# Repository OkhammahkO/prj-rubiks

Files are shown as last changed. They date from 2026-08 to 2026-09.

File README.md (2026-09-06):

# Rubee - Scans and solves a rubiks cube.
A Home Assistant + ESPHome remake of [CUBOTino](https://www.instructables.com/CUBOTino-Autonomous-Small-3D-Printed-Rubiks-Cube-R/)

💬 [Discuss on the Home Assistant Community forum](https://community.home-assistant.io/t/rubee-scans-and-solves-a-rubiks-cube/1024172?u=mahko_mahko)

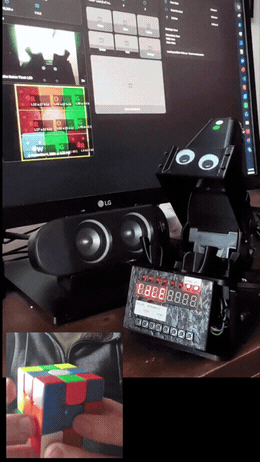
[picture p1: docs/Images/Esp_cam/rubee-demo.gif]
Rubee, the robot, demo


Main differences in this build:
- A HACS component and ESPHome talk to each other and split the work of cube scanning and solving.
- **ESP32-S3-CAM** instead of a Raspberry Pi Zero 2 W (or Zero W) + Pi Camera. Built in LED. ([board](https://github.com/nulllaborg/esp32s3-cam), [buy](https://www.aliexpress.com/item/1005012148685931.html))
- HACS component does colour detection and kociemba solving.
- ESPHome does camera control and implementing the solution.
- **Top-mounted camera with light-blocking hood** - consistent scans regardless of room lighting.
- **TM1638 display with 8 LEDs and buttons + buzzer built into the robot** — live status, audio feedback, and solve/stop/scramble/home controls.

User beware, most of the porting of this project and additional development and docs was vibe coded 💩.

---

## Dashboard

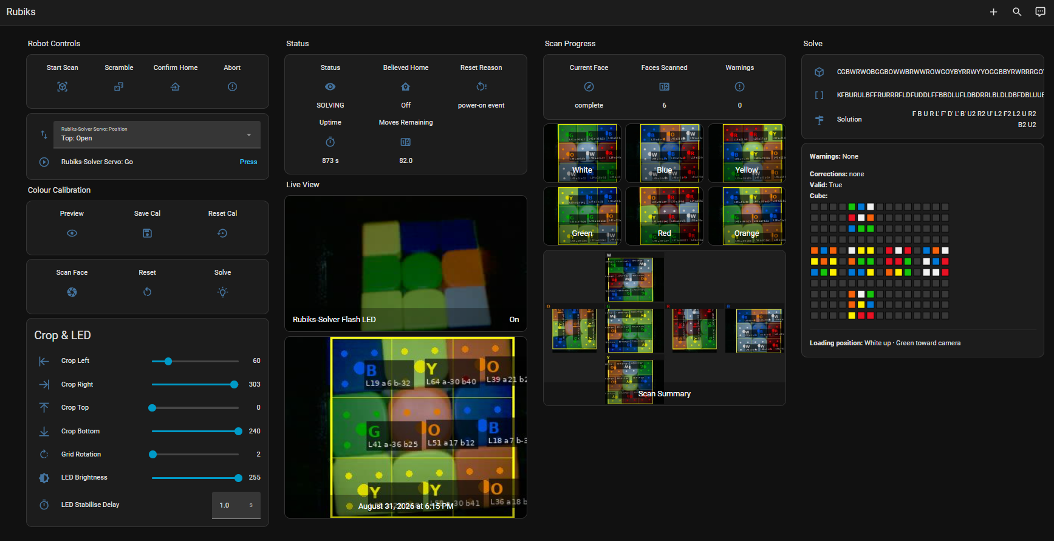
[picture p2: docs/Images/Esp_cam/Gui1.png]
Rubiks dashboard


---

## Setup

 - Don't expect magic out of the box - like the original, servo and colour calibration take some patience to dial in.
  - Assembly generally follows the original - I haven't documented my own variations here. I've been pretty sparse with details of my build and the set-up (except for AI generated docs, some of which might be stale). But happy to develop detail if there's interest.

1. Install the software - HACS component + flash `rubiks-solver.yaml`.
2. Build the hardware - 3D-printed frame and servos per Andrea's "Top" version
3. Calibrate - servo positions/timings, then colour detection.

---

## Docs

- [Architecture / integration spec](docs/spec.md)
- [Robot hardware + ESPHome component](docs/robot.md)
- [Servo tuning reference](docs/servo-tuning.md)
- [Camera/cube orientation model](docs/orientation.md)
- [Collision prevention](docs/collision-prevention.md)
- [TM1638 display/buzzer/buttons](docs/tm1638.md)
- [Feature/entity inventory](docs/features.md)

---

## Extras

- Need a cube? [MoYu RS3M V5 3x3](https://www.aliexpress.com/item/1005006116653775.html)  - cheap, decent, magnetic. Learning on a magnetic cube is way better and should make it easier for the robit too.
- Want to learn to solve one by hand? [This playlist](https://www.youtube.com/playlist?list=PLUprj8UXelXGXLTvO5RaJ92_yJxOwd957) is fun if you've got a little patience.

---

## License / Credits

[MIT](LICENSE) for this project's software, except `custom_components/rubiks` which is [GPLv3+](custom_components/rubiks/LICENSE) — it depends on `twophase` for cube solving, since `kociemba` doesn't install reliably on Home Assistant OS. The physical CUBOTino design/mechanism is Andrea Favero's - see [his Instructables page](https://www.instructables.com/CUBOTino-Autonomous-Small-3D-Printed-Rubiks-Cube-R/) for terms on the design itself. Googly eyes as per  [Andreas Spiess's build](https://youtu.be/G5Ii6ENUXEs).

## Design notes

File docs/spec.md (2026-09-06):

# Rubiks Cube Scanner — Technical Specification

## System Overview

```
ESP32-CAM (ESPHome) ──► HA Integration ──► Kociemba Solver ──► ESP32 Robot (ESPHome)
     camera entity       cube state string    move sequence        motor control
```

Camera scanning and cube-state detection can run standalone (Phase 1/2, manual/webcam
workflow) or driven by the robot (Phase 3, `docs/robot.md`). Both share the same
`SCAN_SEQUENCE` and colour-detection pipeline.

## File Structure

```
custom_components/rubiks/
├── __init__.py           — integration setup, hass.data initialisation, platform list
├── manifest.json         — domain, requirements (Pillow, kociemba)
├── const.py              — DOMAIN, CUBE_COLORS, SCAN_SEQUENCE, SCAN_MOTION,
│                           SCAN_LOADING_HINT, COLOUR_EMOJI, crop keys, device info
├── config_flow.py        — source selection (camera entity or sample image path)
├── cal_store.py          — CalibrationStore: persistent LAB anchor management
├── camera_processor.py   — CIELAB detection, calibration, image annotation,
│                           summary image generation, parity checks
├── solver.py             — kociemba sticker remapping, build_kociemba_faces(),
│                           kociemba_string(), solve()
├── button.py             — Scan Face, Preview Crop, Reset Scan, Save/Reset Calibration,
│                           Solve, Scramble, Robot Start Scan/Stop/Abort/Advance Face
├── image.py               — Last Scan, per-face images, Scan Summary
├── number.py              — Crop Left/Top/Right/Bottom, Crop Rotation, LED Brightness,
│                           LED Stabilise Delay, Scramble Move Count
├── text.py                — LED entity ID override
├── sensor.py               — Cube State, Current Face, Faces Scanned, Scan Warnings,
│                           Kociemba Input, Solution
├── services.yaml         — schema for the rubiks.robot_scan_face / rubiks.solve services
├── rubiks_dashboard.yaml — example Lovelace dashboard
├── strings.json / translations/en.json
└── tests/                  — CIELAB, detection, calibration, sticker remap, kociemba logic
```

## Architecture Decisions

**CIELAB, not HSV.** HSV hue is unreliable on this camera sensor; CIELAB with weighted
distance (`L×1.5, a×2.0, b×2.0`) separates cube colours more robustly. L is weighted
*above* a/b — unusual, but on this specific OV2640 unit Red and Orange are cleanly
separated by lightness more reliably than by chroma (see "Red/Orange Separation" below
for the actual L ranges). A different camera might not have this separation and would
need revisiting.

**Factory reference LAB values** are placeholders, not all camera-tuned. Only R and O
were actually measured on this specific unit (centre-square readings, two sessions,
very consistent); W/Y/B/G are borrowed from a different unit entirely and are expected
to be replaced by Save Calibration after a clean scan on your own camera:

| Colour | L | a | b |
|---|---|---|---|
| W | 66.0 | 16.0 | -15.0 |
| Y | 74.0 | -1.0 | 26.0 |
| R | 35.0 | 50.0 | 22.0 |
| O | 62.0 | 47.0 | 27.0 |
| B | 32.0 | 33.0 | -51.0 |
| G | 45.0 | -15.0 | 14.0 |

Unknown threshold: `_LAB_UNKNOWN_THRESHOLD = 80.0` (weighted units).

**5-point majority vote per cell** (centre + 4 inner corners at ¼ cell offset). Majority
vote tolerates 1-2 glare-affected points outvoting correctly; median LAB would instead
average a desaturated point into the result, risking misclassification.

**Per-session calibration with persistent EMA.** After all 6 faces scan,
`calibrate_faces()` runs a two-round greedy constrained assignment (max 9 per colour) to
refine anchors, blended into persistent storage via EMA (α=0.2) if parity is valid, or
hard-committed via Save Calibration. Centre stickers are locked (pre-assigned before the
greedy competition) since loading-position enforcement makes them ground truth — this
prevents a close competing colour from contaminating round-1 anchor recomputation.
Round-2 anchors use median LAB per cluster (not mean), so a single misassigned outlier
from round 1 doesn't drag the anchor toward it.

**Loading position enforcement.** Face labels are assigned by scan position
(`SCAN_SEQUENCE[len(scanned_faces)]`), not by classifying the centre square — this
eliminates Red/Orange centre-identification ambiguity entirely. A LAB sanity check still
warns if a detected centre is >20 units from its expected reference.

**Crop region and LED brightness as runtime number entities**, not config-flow fields —
tunable live via dashboard sliders with Preview Crop for immediate feedback.

**LED brightness and LAB values**: all absolute L values shift with LED brightness.
Changing brightness significantly requires Reset Calibration → rescan → Save
Calibration to re-establish anchors.

**Kociemba sticker remapping** (`solver.py`) maps each scan position's camera-grid index
to kociemba's canonical face-position index:

| Face | Remap | kociemba canon-top | kociemba canon-left |
|---|---|---|---|
| W (U) | Identity | B-side | L |
| B (B) | 180° | U (=W) | R |
| Y (D) | Identity | F-side | L |
| G (F) | Identity | U | L |
| O (L) | Identity | U | B |
| R (R) | Identity | U | F |

**Phase 3 (robot) key decisions** — full detail in `docs/robot.md` and
`docs/collision-prevention.md`:
- Kociemba runs in HA, not on the ESP32 (two-phase pruning tables need 10-20MB RAM).
- Servo step queue is non-blocking, pre-planned into `std::vector<ServoStep>`, drained
  one entry per `loop()` tick.
- Raw MicroPython PWM duty (0-1023, from `Cubotino_settings.txt`) converts to ESPHome's
  -1.0..1.0 via `duty_to_esphome()` in C++ only.

**Already-solved short-circuit**: `solve()` checks `_is_solved()` and returns `""`
directly before ever calling the underlying solver, rather than relying on it to
handle a trivial already-solved input correctly.

## Shared Data (`hass.data[DOMAIN][entry_id]`)

| Key | Type | Description |
|-----|---|---|
| `scanned_faces` | `dict[str, list[str]]` | face_label → 9 colour codes |
| `face_scans` | `dict[str, FaceScan]` | dataclass per face (colours + LAB readings) |
| `face_annotated_images` | `dict[str, bytes]` | per-face annotated JPEG |
| `calibration_result` | `CalibrationResult \| None` | most recent calibration |
| `summary_image` | `bytes \| None` | cross-net-layout JPEG (see `_SUMMARY_NET_POSITIONS`) |
| `last_annotated_image` | `bytes \| None` | most recent scan or preview |
| `image_size` | `tuple[int, int] \| None` | (width, height) of the last-loaded image, feeds crop slider max |
| `scan_warnings` | `list[str]` | current plain-English warnings |
| `crop_entities` | `dict[str, CropNumberEntity]` | registered crop number entities, keyed by entity key |
| `led_entity_id` | `str \| None` | configured LED light entity ID |
| `led_brightness_entity` | `LedBrightnessEntity \| None` | registered LED Brightness entity |
| `led_stabilise_delay_entity` | `LedStabiliseDelayEntity \| None` | registered LED Stabilise Delay entity |
| `scramble_move_count_entity` | `ScrambleMoveCountEntity \| None` | registered Scramble Move Count entity |
| `cal_store` | `CalibrationStore` | persistent LAB anchor store |
| `kociemba_faces` | `dict[str, list[str]] \| None` | built from `scanned_faces` after calibration |

The solve result isn't stored in `hass.data` — it only ever exists transiently in the
`rubiks_solved` event payload and in the Solution sensor's own entity state.

## Pipelines

**Colour detection**: image → optional crop → 3×3 grid → per-cell 5-point CIELAB
classification + majority vote → `override_centre` (loading-position label) →
`_annotate_image()` → `FaceScan`.

**Calibration** (after 6th face): build anchors from centres → greedy round 1 (centres
locked) → recompute anchors (median) → greedy round 2 → confidence margins → flag
low-confidence (<0.15 margin) → `check_cube_parity()` → `CalibrationResult` → EMA update
if valid → `build_kociemba_faces()` → fire `rubiks_calibrated`.

**Solver** (Solve button): `kociemba_string()` → `_is_solved()` short-circuit →
`twophase.solver.solve()` via executor job (see `docs/features.md` "Solver
dependency") → solution string or `""` ("Already solved!") → fire `rubiks_solved`.

## Scan Sequence (Phase 1/2 manual/webcam)

Loading position: **White facing camera, Blue at top, Orange on left.**

| Step | Face | Motion | Camera-top | Camera-left | kociemba face |
|---|---|---|---|---|---|
| 1 | White | Load | Blue | Orange | U |
| 2 | Blue | Tilt backward | Yellow | Orange | B |
| 3 | Yellow | Tilt backward | Green | Orange | D |
| 4 | Green | Tilt backward | White | Orange | F |
| 5 | Red | Rotate left | White | Blue | R |
| 6 | Orange | Rotate 180° | White | Green | L |

Matches `SCAN_SEQUENCE = ["W","B","Y","G","R","O"]` and `SCAN_MOTION` in `const.py` —
the same list the robot service schema validates against.

## Validation Checks

| Check | When | Action |
|---|---|---|
| LAB centre vs expected colour | Each scan | Warning if distance > 20 units |
| No colour > 9 across scanned faces | After each scan | Warning |
| Each colour appears as centre once | After face 6 | Warning if missing/unexpected |
| Centre sticker matches face label | After calibration | Warning (Red/Orange confusion indicator) |
| Exactly 54 stickers, 6×9 | After calibration | `parity_valid`/`parity_error` |
| Structural cube validity | After calibration | `diagnose_cube_string()` |
| Low-confidence stickers | After calibration | Flagged, not blocking |
| Valid cube state | On Solve | Solver returns an error string if impossible (not an exception) |

## Services

| Service | Description | Returns |
|---|---|---|
| `rubiks.robot_scan_face` | Illuminate → capture → detect → store for one face | — |
| `rubiks.solve` | Run kociemba solver against stored face scans | `{solution, move_count, cube_string}` on success; on failure `{error, solution: "", move_count: 0}` (no `cube_string`) |

## Events

| Event | Payload | Fired by |
|---|---|---|
| `rubiks_face_scanned` | `{face, colors, warnings}` | ScanFaceButton |
| `rubiks_scan_rejected` | `{}` | PreviewCropButton |
| `rubiks_scan_reset` | `{}` | ResetScanButton, RobotStartScanButton, RobotAbortButton |
| `rubiks_calibrated` | `{parity_valid, corrections, low_confidence, anchors_saved, kociemba_string}` | ScanFaceButton |
| `rubiks_solved` | `{solution, move_count, cube_string}` | SolveButton, `rubiks.solve` |
| `rubiks_calibration_saved` / `rubiks_calibration_reset` | — | Save/Reset Calibration buttons |
| `rubiks_robot_start_requested` / `_stop_requested` / `_advance_face_requested` | `{}` | Robot buttons |

## Cube State String Formats

**Human-readable** (Cube State sensor): 54 chars, scan order (`W B Y G R O`), letters
`W Y R O B G`.

**Kociemba Input sensor**: 54 chars, kociemba face order (`U R F D L B`), letters
`U R F D L B`. Produced by `solver.kociemba_string(kociemba_faces)`.

## Red/Orange Separation — Camera-Specific Notes

Hardest pair to separate (adjacent hue, differ mainly in lightness/saturation). On this
camera: Red L≈14-38, Orange L≈40-63 (`camera_processor.py`'s `_L_WEIGHT` comment — the
single source of truth for these ranges; older revisions of this doc quoted slightly
different numbers, now removed to avoid drifting out of sync again) — only a small gap
between the darkest Orange corner and brightest Red corner, so a/b still matters for
borderline cells even with L weighted higher.

Centroid-based anchors (post-calibration) classify borderline dark-Orange corners
correctly; centre-square-only anchors place the decision boundary too high and risk
misclassifying them as Red on the first scan, before calibration's two-round greedy
corrects it.

Glare on Red can desaturate b toward White's range; majority vote tolerates this unless
3+ of the 5 sample points are affected.

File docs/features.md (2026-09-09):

# Rubiks Cube Scanner — Feature Tracking

## Phase 1 — Cube State Detection ✅

Reliably scan all 6 faces and produce a valid 54-character cube state string.

**Detection**: CIELAB classification (`L×1.5, a/b×2.0` weighted distance), 5-point
majority vote per cell (centre + 4 inner corners, glare-tolerant), median LAB per cell
for display.

**Loading position enforcement**: fixed scan sequence `SCAN_SEQUENCE = ["W","B","Y","G","R","O"]`;
face label assigned by sequence position, not centre classification — eliminates
Red/Orange centre-identification ambiguity. LAB sanity check warns if a detected centre
deviates >20 units from its expected reference.

**Calibration**: per-session greedy constrained assignment (max 9/colour) with centroid
refinement; confidence margins flag low-confidence stickers (<0.15); EMA blend (α=0.2)
persisted after every parity-valid session; manual Save/Reset Calibration buttons;
survives restarts (`.storage/rubiks_cal_<entry_id>`).

**Validation**: running colour-count check, centre-uniqueness check (after face 6),
parity check (exactly 9 of each colour), `parity_valid`/`parity_error` sensor attributes.

**Entities**: Scan Face / Preview Crop / Reset Scan / Save Calibration / Reset
Calibration buttons; Last Scan, 6 per-face images, Scan Summary (cross-net layout via
`_SUMMARY_NET_POSITIONS`) images; Crop Left/Top/Right/Bottom, Crop Rotation, LED
Brightness, LED Stabilise Delay numbers; LED entity ID override text; Cube State,
Current Face, Faces Scanned, Scan Warnings sensors.

**Annotated overlay**: crop boundary, 3×3 grid, colour-coded sample dots, per-cell
colour label + LAB values, semi-transparent legibility backgrounds. Overlay points are
un-rotated back to the original image frame before drawing (`_unrotate_point()`) so they
align correctly even when `Crop Rotation` is non-zero.

**Config**: options flow allows changing source/camera entity without re-adding the
integration, plus an optional LED entity override selector. LED entity auto-discovery
resolves the camera's device, finds `light` domain entities on it, auto-selects if
exactly one.

**Testing**: run `pytest custom_components/rubiks/tests/ -v` for the current count
(colour detection, calibration, solver logic) — not duplicated here since it drifts
every time a test is added. 13 synthetic sample images in `tests/samples/`.

**Open**: cube net display verification.

---

## Phase 2 — Solver ✅

Take the cube state string and produce a move sequence.

`solver.py`: camera grid index → kociemba face-position index remap per scan position
(`CAMERA_TO_KOCIEMBA_REMAP` for Phase 1/2, `ROBOT_CAMERA_TO_KOCIEMBA_REMAP` for the robot
— see `docs/orientation.md`); populates `kociemba_faces` after calibration.
`solver.solve()` wraps `twophase.solver.solve()` via `async_add_executor_job` (not
the `kociemba` package — see "Solver dependency" below), with a `_is_solved()`
short-circuit before calling it either way. Kociemba Input and Solution sensors expose
the string and move sequence. Verified against a physical cube end-to-end.

**Solver dependency**: uses `twophase` (pure Python, GPLv3+ — see
`custom_components/rubiks/LICENSE`), not `kociemba`. `kociemba` ships no Linux wheels
and its C-extension build fails on Home Assistant OS's sandboxed, musl-based install
environment; `twophase` needs no compiled extension at all, at the cost of needing its
pruning tables pre-built rather than generated on first use (30+ minutes in pure
Python). Shipped compressed as `custom_components/rubiks/twophase_tables.tar.gz`
(~33MB vs ~70MB raw) and extracted to a sibling `twophase_tables/` directory
(gitignored — a local runtime artifact, not tracked) the first time `solve()` runs
after install/update — plain stdlib `tarfile` decompression, no compiler involved, so
none of the HAOS build issues that ruled out `kociemba` apply. `twophase.defs.FOLDER`
is redirected to that extracted path before first import — see `solver.solve()`'s and
`_ensure_tables_extracted()`'s docstrings.

**Open**: cube net display verification.

---

## Phase 3 — Robot

Physically solve the cube using an ESP32-S3 robot adapted from CUBOTino. Automates both
scanning and solution execution. Architecture: `docs/robot.md`. Cross-servo timing:
`docs/collision-prevention.md`.

**Kociemba runs in HA, not the ESP32** — the two-phase pruning tables need 10-20MB RAM;
the ESP32-S3 has 8MB PSRAM.

### ESP32-S3 component

External C++ component (`esphome/components/rubiks_solver/`): `moves.h` (port of
`Cubotino_moves.py` — orientation tracking, `MOVES_TABLE`, `robot_required_moves()`),
`rubiks_solver.cpp` (`plan_flip_/spin_/rotate_/ensure_cover_*`, `plan_solution_()`,
non-blocking `loop()`). Servo position/timing defaults from `Cubotino_settings.txt`,
converted to ESPHome -1.0..1.0 via `duty_to_esphome()`. All values YAML-configurable
live via HA number entities. `auto_detach_time: 5s` on both servos (must exceed the
longest step duration to avoid mid-travel dropout).

### Scan flow

`start_scan()`/`advance_scan()` plan each face's moves (`SCAN_FACES = {"W","B","Y","G","R","O"}`,
matching `SCAN_SEQUENCE`), fire `esphome.rubiks_face_ready` per face, and after all 6,
run a `flip → spin_home → flip` return-to-start sequence (no `rotate`, so no D-layer
side effect) before firing `esphome.rubiks_scan_complete`. The robot bridge
(`custom_components/rubiks/robot_bridge.py`) relays `rubiks_face_ready` →
`rubiks.robot_scan_face` → `face_scan_done`, and `rubiks_scan_complete` →
`rubiks.solve` → `execute_solution`.

### Solve flow

`execute_solution()` translates the kociemba string through `moves.h` into a full servo
step queue, drained non-blocking by `loop()`. Fires `esphome.rubiks_solve_done` on
completion and returns straight to `IDLE` (no separate lingering `DONE` state).

### ESP32 API actions / events

Actions (HA→ESP32): `start_scan`, `face_scan_done`, `execute_solution` (returns
`{accepted, move_count}` via `api.respond`), `stop`, `confirm_safe_and_home`.
Events (ESP32→HA): `rubiks_face_ready {face}`, `rubiks_scan_complete`,
`rubiks_solve_done`.

### Safety / state machine

Full mechanism detail lives in the dedicated docs, not here — this is just the
inventory of what exists:

- Unclean-reset boot gate + `needs_confirm_before_move_` (also set when `stop()`
  interrupts a non-`IDLE` state) — `docs/robot.md` "Safety and timing".
- Two-layer cross-servo timing guard (plan-time + dispatch-time) —
  `docs/collision-prevention.md`.
- `SERVO_TEST` state drains a planned step queue then returns to `IDLE`; used by every
  diagnostic test button and the boot glide.
- `believed_home_` / `binary_sensor.rubiks_solver_believed_home` — optimistic home
  tracking, hard-blocks `start_scan()`/`execute_solution()` like
  `needs_confirm_before_move_` — `docs/servo-tuning.md` "Believed-home safeguard".

### Diagnostic entities

`solver_status` text sensor drives the TM1638 display, RTTTL beeps, and LED routines —
full status→feedback mapping in `docs/tm1638.md`. Servo test buttons (raw position
writes + planned cycles: rotate/spin/flip/scan-cycle/return-home), plus one shared
"Test: Run" button that dispatches based on a select entity's 18 single
kociemba-notation move options (`U`/`U2`/`U3`.../`B3`) — calls `execute_solution()`
directly for isolated move testing. 16 of 17 conceived calibration number entities are
live (`Top: Release Offset` remains commented out — its parameter sits at 0, a no-op
matching `Cubotino_settings.txt`'s own default); current values in `docs/servo-tuning.md`.
`Speed Multiplier` scales all step durations at plan time (currently 1.0× — the jam
cause turned out to be a servo calibration issue, not timing, so the earlier
precautionary bump was reverted). `reset_reason` diagnostic sensor.

### Versioning

`INTEGRATION_VERSION` (`const.py`) reads `manifest.json` at import time — single source
of truth, shown as `sw_version` on every HA device page. `esphome.project.name`/`version`
does the same for the ESP32 device page.

### HA side

`rubiks.robot_scan_face` service (`{face}`) runs illuminate→capture→detect→store,
schema-validated against `SCAN_SEQUENCE`. `rubiks.solve` service
(`SupportsResponse.OPTIONAL`) shared with the Solve button via `async_handle_solve()`.
4 robot control buttons (Start Scan / Stop / Abort / Advance Face) fire HA events rather
than calling ESPHome services directly, so automations are the single coupling point.

**Open**: soft guard in `ScanFaceButton` to refuse a press while the robot is scanning —
low priority.

### Hardware

Pinout, power, and calibration history: `docs/robot.md` "Hardware",
`docs/servo-tuning.md`.

### TM1638 display + buzzer + LEDs

Display, buzzer, LED routines, physical-button actions, transient error/rejection
feedback, and brightness control all implemented — full detail and current
status→feedback mapping in `docs/tm1638.md`. A solve-timer alternation was tried and
rolled back — see `docs/tm1638.md`'s "Moves Remaining" note.

### Future features (post-launch)

Not yet implemented, roughly in priority order: solve statistics sensors (time, move
count, personal best, history), calibration-health monitoring (auto-prompt
recalibration on drift or LED brightness change), dry-run mode (log moves without
moving servos), demo/fun modes (scramble-solve loop, speed leaderboard). True
standalone-without-HA operation isn't planned — the TM1638 button actions route
through HA, they don't bypass it.

**Live-updating cube state diagram** — have `CubeStateSensor`'s emoji cube net
(`sensor.py`'s `_cube_net()`) update move-by-move as a solve executes, instead of only
showing the static post-scan snapshot it does today (refreshed once on
`rubiks_calibrated`). The per-move facelet transform is essentially free — `twophase`
(already a dependency) applies one move via `FaceCube.from_string()` →
`.to_cubie_cube()` → `.multiply(basicMoveCube[Color.U/R/F/D/L/B])` →
`.to_facelet_cube().to_string()`, no hand-written permutation tables needed. The real
cost is ESP32-side: firmware only tracks progress in robot-primitive units
(flip/spin/rotate, via `moves_remaining`/`mark_action_boundary_()`) — there's no signal
today for "which original solve move just finished." Needs a second, coarser boundary
tracker (one entry per kociemba move, not per robot action) plus a new HA event fired
per completion, mirroring the existing `moves_remaining` pattern — an area
`docs/tm1638.md`'s "Fixed bug" note shows is easy to get subtly wrong. Same caveat as
`believed_home`: with no physical position feedback anywhere in this project, the
diagram would show the *intended* state assuming perfect execution, not a verified one.

#### Scrambler — implemented (robot-efficient version)

No firmware changes — reuses `execute_solution()` entirely, so every existing guard
(`state_ == IDLE`, `needs_confirm_before_move_`, `believed_home_`) applies automatically,
same as a real solve.

- **Generator**: `generate_efficient_scramble()` (`efficient_scramble.py`) — unlike a
  plain random-move scramble (picking faces uniformly at random), this biases each pick
  toward whichever face is currently reachable *without* a flip. Each kociemba notation
  move translates to 2-7 physical robot actions depending on which face is currently
  reachable (a Python port of `moves.h`'s translation table, `ROBOT_MOVES_TABLE`, scores
  each candidate); picking randomly wastes most of a scramble's cost on faces that
  happen to need reorienting first. Cuts the average robot-action count by roughly a
  third versus the old plain-random generator, at the same scramble length. Still never
  repeats the same face on consecutive moves (same rule the old generator used — avoids
  wasteful runs like six `R1`'s in place of one `R2`).
- **Hardness verification**: every candidate is applied to a solved cube (via
  `twophase`'s own verified move algebra — `CubieCube`/`basicMoveCube`, not a hand-rolled
  permutation table) and run through the real solver (`solver.solve()`) before being
  accepted, rejecting anything that solves in fewer than `MIN_SOLUTION_LENGTH` (17)
  moves — a cheap, biased generator must never also produce an under-scrambled cube.
  Resolves in 1-5 attempts in practice (capped at `MAX_ATTEMPTS`), so it's cheap enough
  to run synchronously via `hass.async_add_executor_job`, same as this integration's
  other CPU-bound work (`calibrate_faces`, `detect_face_colors`).
- **Move count**: `Scramble Move Count` number entity (`number.py`), range 15-50,
  default **26** — works at any configured length, since the generator/verifier don't
  assume a fixed count.
- **Entity**: `ScrambleButton` (`button.py`) generates the string in `async_press()` and
  fires `rubiks_scramble_requested` with `{solution}` as event data — same decoupling
  convention as `RobotStartScanButton`/etc. The robot bridge
  (`custom_components/rubiks/robot_bridge.py`) relays it to
  `esphome.<device>_execute_solution`.
- Tests: `tests/test_button.py` (real, unmocked — correctness here depends on the
  actual `twophase` solver's difficulty verification).

**Lowest priority — code health, no behavior change**: split `button.py` into
`scan_pipeline.py` (shared async helpers) + a thinned `button.py` (just entity
classes), and `camera_processor.py` into `calibration.py` (calibration/validation) +
a thinned `camera_processor.py` (detection/annotation). Pure readability/maintainability
for whoever else works on this later — not blocking anything currently.

---

## Known Issues / Limitations

| Issue | Notes |
|---|---|
| Red/Orange separation | Hardest colour pair on this camera (see `docs/spec.md` "Red/Orange Separation" for the actual L ranges) — loading-position enforcement assigns labels by scan position, not centre classification, eliminating the ambiguity; LAB warning still fires if a scan looks wrong |
| White centre has brand logo | 5-point majority vote handles it but confidence may be low |
| Full permutation parity not checked | The solver rejects unsolvable states implicitly (returns an error rather than a bogus solution) |
| LED never auto-turns-off | User controls it via normal HA UI |
| No real servo position feedback | Neither this project nor the original CUBOTino has any — see `docs/collision-prevention.md` |

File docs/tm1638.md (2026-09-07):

# TM1638 Display & Buzzer

8-digit 7-segment LED display with 8 physical buttons and (on most modules) 8 individual
LEDs, plus a separate RTTTL piezo buzzer. Hardware tested; pins confirmed working.

## Hardware

| Function | Pin |
|---|---|
| TM1638 STB | GPIO 14 |
| TM1638 CLK | GPIO 41 |
| TM1638 DIO | GPIO 42 |
| Buzzer (RTTTL, LEDC ch 6) | GPIO 44 |

GPIO42 briefly looked dead during assembly — turned out to be a stray wire in the
harness shorting DIO to ground, not a damaged pin. See `docs/robot.md` "Hardware"
for the full diagnosis (a raw GPIO toggle test that bypasses the TM1638 driver
entirely). GPIO47 is a confirmed-working spare if DIO ever needs to move again.

The 8 LEDs are exposed as diagnostic switches (`TM1638 LED 1`-`8`, plus a `TM1638 LEDs
1-6` group switch) and driven three ways: each button's own LED flashes momentarily on
that button's press (see "Physical buttons" below); LEDs 1-6 run one of several status
routines tied to `solver_status` (see "LED routines" below); LEDs 7-8 are dedicated
status dots (home/safety, API connectivity) never touched by the shared routines. The 8
buttons are exposed as diagnostic binary sensors (`TM1638 Button 1`-`8`). Every button
beeps and flashes its own LED on press; buttons 1-4 also trigger a real action, 5-8 are
still placeholder feedback only.

## Current implementation

**Display** (`display: platform: tm1638` in `rubiks-solver.yaml`): shows the
`solver_status` text sensor, right-padded to 8 characters, refreshed every 500ms.
Possible values: `IDLE`/`LOAD`, `SCAN N`, `FACE Nc` (c = colour letter), `HOMING`,
`SCAN END`, `SOLVING`, `DONE`, `CHK ARM`. Priority chain, each overriding the plain
status text below it:

| Priority | Shown when | Text |
|---|---|---|
| 1 | First 2s after boot | `RUBEE` |
| 2 | First 2s after HA connects (fires on every reconnect, not just boot) | `READY` |
| 3 | HA API disconnected (live-polled every refresh, so it covers a slow/stuck boot too) | `LOST API` |
| 4 | A transient message is active (`show_transient_message()` in `rubiks_solver.cpp`) | see "Transient messages" below |
| 5 | Status is exactly `SOLVING` | `LEFT nnn` — the live `Moves Remaining` sensor |
| 6 | Status is `IDLE` and the robot is believed home | `LOAD` — prompt to place a cube and start a scan |
| 7 | Otherwise | the plain `solver_status` text |

`RUBEE`/`READY`/`LOST API` were chosen to avoid the TM1638's worst 7-segment glyphs
(`M`, `V`, `W`, `X` all render ambiguously or identically to other characters) — see the
display lambda's own comments for the exact segment reasoning. `LOAD` (not `READY`,
already taken by priority 2) fills the same "waiting for a cube" role during ordinary
idle time.

**Transient messages** (`show_transient_message(msg, duration_ms)` in
`rubiks_solver.h`/`.cpp`): briefly overrides the display without touching
`solver_status`/the state machine — a `set_timeout("transient_msg", ...)` clears it
automatically, and calling it again while one is already showing just restarts the
timer rather than queuing. Used for feedback that isn't a real state transition:

| Trigger | Message | Duration |
|---|---|---|
| `start_scan()`/`execute_solution()` called while not `IDLE` | `BUSY` | 1500ms |
| `start_scan()`/`execute_solution()` called needing `confirm_safe_and_home()` first (unconfirmed after a reset/abort, or not believed home) | `NOT HOME` | 1500ms |
| `execute_solution()` planned zero steps (cube already solved) | `SOLVED` | 1500ms |
| HA reports a bad scan (`rubiks_calibrated` event, `parity_valid: false`) — via the `show_message` API action, called from `robot_bridge.py` | `SCAN ERR` | 3000ms |
| HA reports a failed solve after scanning (`robot_bridge.py`'s `_on_scan_complete`) — same `show_message` action | `SOLVE ERR` | 3000ms |

The two HA-reported cases use a longer dwell than the firmware's own, since they arrive
after a round trip to HA and are more likely to matter to someone not watching the
display live when it happens.

**Moves Remaining** (`moves_remaining_sensor:` on the `rubiks_solver` component):
counts down from the full robot-action count (flips/spins/rotates — the same count
reported to HA in `execute_solution`'s `move_count` response) to 0 as
`execute_solution()` progresses, via `mark_action_boundary_()` calls placed in
`plan_flip_`/`plan_spin_`/`plan_rotate_` (`rubiks_solver.cpp`). Purely additive
bookkeeping — it observes `step_idx_` crossing precomputed boundaries and never
influences step timing or servo positions, so it can't introduce a collision risk.
Only meaningful while `SOLVING`; stale (holds the last solve's count) otherwise.

**Fixed bug (2026-09-07, confirmed on hardware)**: read `0` for the entire duration of both a real solve and a
scramble, rather than counting down — first noticed once a since-reverted solve-timer
display feature made it obvious the number wasn't moving. Root cause, confirmed via a
live diagnostic log (`step_idx=5 robot_actions_done=3/112 robot_move_count=0
remaining=-3`): `action_boundaries_`/`robot_actions_done_` were tracking the active
112-action plan correctly, but `robot_move_count_` had been zeroed *after* planning —
by `execute_solution()`'s own "not idle" rejection guard, which a second, rejected
`execute_solution()` call hits when it arrives while a previous solve/scramble is still
running, since `robot_move_count_` was shared between "this call's own api.respond
outcome" and "the live plan's action count." Fixed by splitting those into separate
fields (`last_call_accepted_`/`last_call_move_count_` for the API response,
`robot_move_count_` now touched only by `plan_solution_()`), so a rejected call can no
longer corrupt an in-flight run's countdown.

Still open: *why* `execute_solution()` is being called twice in the first place —
worth ruling out stale/duplicated event listeners in `robot_bridge.py` from repeated HA
integration reloads (vs. a full restart) during iteration; a full HA restart clears
that if so. The `moves_remaining:` diagnostic log added while chasing this (in the
`loop()` boundary-crossing block) is being kept permanently rather than reverted — it's
one line per action (not per step), and cheap insurance against a repeat.

**Physical buttons** (`TM1638 Button 1`-`8`, `binary_sensor: platform: tm1638` in
`rubiks-solver.yaml`): all 8 beep and flash their own LED on press. Buttons 1-4 also
trigger a real action:

| Button | Action | Mechanism |
|---|---|---|
| 1 | Start Scan | `homeassistant.action`: `button.press` on `button.rubiks_cube_scanner_robot_start_scan` |
| 2 | Abort | `homeassistant.action`: `button.press` on `button.rubiks_cube_scanner_robot_abort` |
| 3 | Scramble | `homeassistant.action`: `button.press` on `button.rubiks_cube_scanner_scramble` |
| 4 | Confirm Safe & Home | Local — calls `confirm_safe_and_home()` directly, same as the existing HA-side template button. Its only guard is `state_ != IDLE`, so despite the name this already doubles as a plain "re-home now" control for routine use (e.g. after manually nudging the cube holder), not just unclean-reset recovery. |

Buttons 5-8 are still placeholder (beep + flash only) — the "Solve" step doesn't need
its own button since the robot bridge's solve dispatcher
(`custom_components/rubiks/robot_bridge.py`) already fires it automatically once
scanning finishes; "Advance Face" stayed HA-dashboard-only since it's a debug aid, not
a normal-use action.

**Why route Start Scan/Abort/Scramble through `homeassistant.action` instead of
calling the equivalent ESPHome action (`start_scan()`/`stop()`) directly**: the HA-side
buttons do more than their firmware counterparts. `RobotStartScanButton`/
`RobotAbortButton` also clear stale scan state (`scanned_faces` etc.) before/alongside
triggering the robot — a bare `esphome.rubiks_solver_start_scan` call skips that,
risking a previous incomplete scan's leftover data bleeding into the new one.
`homeassistant.action: button.press` on the exact HA entity_id runs the identical code
path as clicking it on the dashboard, so there's one source of truth instead of two
implementations that can drift. `confirm_safe_and_home()` has no such HA-side wrapper
(no scan state involved), so a direct local call is already complete and correct.
Requires ESPHome 2025.10.0+ (`homeassistant.action` bidirectional response handling) —
this project is on 2026.7.2, so it's available.

**Also requires enabling it on the HA side, per device**: Settings → Devices &
Services → ESPHome → this device → gear/Configure icon → "Allow the device to perform
Home Assistant actions". Off by default. Without it, the ESP32 sends the action
request but HA never subscribed to receive it, so it's silently dropped — firmware
logs a warning (`Home Assistant action '...' dropped; ...`) but nothing else visibly
happens, which looks identical to a firmware/wiring bug from the button/beep/LED side
(those all still fire fine, since they don't depend on this toggle at all).

**Each button's very first press after boot did nothing** (no beep, no flash, no
action) — every subsequent press worked fine. Root cause: ESPHome's
`trigger_on_initial_state` defaults to `false`, so `on_press` doesn't fire on a
binary_sensor's first-ever published state after boot (treated as establishing the
baseline, not a real transition) — only on later genuine changes. Since each button
tracks this independently, every button's own first press was silently swallowed.
Two earlier theories (a `delayed_on: 10ms` filter race, and a state-subscription
timing gap on `homeassistant.action`) were investigated and partially addressed along
the way, but neither was the actual cause — this setting was. Fixed by adding
`trigger_on_initial_state: true` to all 8 `TM1638 Button` entities.

**Rejection feedback**: each of the three `homeassistant.action` calls (buttons 1/2/3)
has `on_error`/`on_success` handlers. On failure, the error trigger's `error` variable
(a `std::string` — the actual HA-side rejection reason) is logged, and `beep_error`
plays a distinct low double-blip, audibly different from `beep_click`, so a rejected
press no longer looks identical to nothing happening. On success, only a log line is
recorded (no extra beep — `beep_click` already confirmed the press, and the robot's
own resulting behavior, e.g. starting a scan, is the real confirmation).

**`Test: Display Hello`** (diagnostic button) — bare hardware check, writes `"HELLO"`
directly to the status text sensor the display already mirrors, bypassing the solver's
state machine entirely (no servo motion, no beep — `"HELLO"` doesn't match any RTTTL
condition). If this doesn't show up, the problem is display wiring (GPIO 14/41/42), not
firmware logic — useful as a first check during initial assembly, independent of
whether the rest of the component is even working yet.

**Buzzer** (`rtttl:` component, driven by `on_value` on the same `solver_status` sensor):

| Status | Sound |
|---|---|
| `FACE N` | single short beep |
| `HOMING` | 2 low beeps (`g4,p,g4`) |
| `SCAN END` | 3 beeps at the original pitch (`c6,p,c6,p,c6`) |
| `DONE` | short ascending 4-note melody |

`HOMING` and `SCAN END` deliberately differ in both pitch *and* beep count, not just
pitch, so they're distinguishable on a small piezo buzzer. Both are timed to land in
genuine pauses rather than over servo motion — see
`docs/collision-prevention.md` ("Settle pads at the scan-return boundary") and the
1500ms settle delay at the top of the solve dispatcher in
`custom_components/rubiks/robot_bridge.py` for how each is kept clear of the motion
around it.

**LED routines** (`script:` entries in `rubiks-solver.yaml`, triggered from the same
`status_sensor` `on_value` block as the beeps above): each status gets a visually
distinct pattern across the 8-LED bar, so the robot's state reads at a glance without
looking at the display.

LEDs 1-6 only — 7 and 8 are dedicated status dots (see below) and are deliberately
excluded from every shared routine, via a `switch: platform: template` group entity
(`TM1638 LEDs 1-6`) that the scripts call instead of repeating a 6-line block.

| Status | Routine | Script id |
|---|---|---|
| `FACE Nc` | Light that face's LED and leave it on — a 1-6 progress bar builds across the scan | (inline, `atoi()`s the status string starting after `"FACE "` — stops at the first non-digit, so the trailing colour letter doesn't affect parsing) |
| `HOMING` | Reverse "collapse" — LEDs 6→1 turn off in sequence, mirroring the cube physically returning home | `homing_led_collapse` |
| `SCAN END` | One quick marquee chase across 1-6, then off | `scan_end_chase` |
| `SOLVING` | Continuous back-and-forth "Cylon" sweep across 1-6 | `solving_led_sweep` |
| `DONE` | Forward chase + reverse chase + a final all-on flash (1-6) | `done_celebration` |
| `CHK ARM` | Slow alternating blink of LEDs 1/3/5 vs 2/4/6 — deliberately not a chase, so it reads as "different, needs a human" | `chk_arm_led_blink` |
| `IDLE` | LEDs 1-6 off (safety net — an abort mid-scan/mid-solve can reach `IDLE` without passing through `HOMING`/`DONE`, whose routines clean up after themselves) | `idle_led_reset` |

`solving_led_sweep` and `chk_arm_led_blink` are the two continuous status-text-driven
routines — each uses a `while:` action whose condition re-checks the live
`solver_status` on every cycle, so it self-terminates (and clears its LEDs) the instant
status changes, with no external stop signal needed. All of these scripts are LED-only
side effects with no servo/timing interaction, so none of them can affect step timing
or introduce a collision risk regardless of how long an animation runs.

**Dedicated status dots (LEDs 7-8)** — unlike the routines above, these aren't tied to
`solver_status` text at all; they're driven by a 1s `interval:` watchdog that polls a
live condition directly (each guarded with `is_running()` so it starts/stops exactly
once per transition):

| LED | Solid on | Blinks (200ms) | Off | Script id |
|---|---|---|---|---|
| 7 | Believed home | `IDLE` but not believed home — catches `test_scan_cycle()` leaving the robot parked at a scan face, or a `stop()` that interrupted a non-`IDLE` sequence, neither of which is the narrower unclean-reset case `CHK ARM` already covers. See `docs/servo-tuning.md` "Believed-home safeguard". | Actively scanning/solving — not home yet, but not a problem either | `not_home_blink` |
| 8 | HA API connected | HA API disconnected. A plain `on_client_disconnected` trigger would miss a cold boot that hasn't connected even once yet (no prior connection to "lose"), so this polls `global_api_server->is_connected()` instead — the same reasoning as the display's `LOST API` text below. | (never — always either on or blinking) | `api_lost_blink` |

Both are excluded from every status-text routine above, so nothing else ever
overrides them. Buttons 7/8's own press-flash (see "Physical buttons" below) still
briefly lights its own LED regardless — a minor, accepted cosmetic overlap since
7/8 are otherwise unassigned placeholder buttons.

## Display brightness

`Display Brightness` (`number: platform: template` in `rubiks-solver.yaml`, 0-7,
`restore_value: true`) calls `id(tm1638_display).set_intensity()` live — mirrors the
camera's `LED Brightness` on the HA side. `intensity: 1` in the `display:` block is
just the cold-boot fallback before this entity's restored value applies.

Deliberately **not** implemented: a "computing solve" status shown while HA runs the
solver between `SCAN END` and `SOLVING` — would need a new HA→ESP32 call just for that
one status update, real complexity for a minor nicety.

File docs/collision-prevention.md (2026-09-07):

# Preventing Competing-Move Collisions

How the top servo (flip lever) and bottom servo (turntable) are kept from colliding.

## The physical mechanism

Full description in `docs/robot.md` "Physical Mechanism" — short version: the top
servo drives two different things depending on position (a cover that clamps down from
above, and a separate smaller flip lever that swings up from below, through slots in
the turntable), and the bottom servo drives the turntable the cube always sits in.

Both the cover *and* the flip lever need the turntable at a slot-aligned angle
(home/CW/CCW) to reach the cube safely — the cover because it clamps down around
whatever's sitting in the turntable, the flip lever because it has to physically pass
through the turntable's slots. So a collision can happen from any of:

1. The **cover** closing while the turntable isn't slot-aligned.
2. The **flip lever** swinging up while the turntable isn't slot-aligned — same
   underlying risk as (1), just the other top-servo position that reaches through the
   turntable.
3. The turntable moving before whichever of the two has actually finished clearing,
   even when both end positions were correct.

Position correctness (1 and 2) is handled by the planner always using slot-aligned
targets (`docs/robot.md`); everything below is about timing (3).

## Two independent timing layers

**Plan-time** (`append_step_()`, `rubiks_solver.cpp`): tracks "how long does the other
servo's most recently queued move still need" (`pending_bottom_travel_ms_` /
`pending_top_travel_ms_`) and stretches the current step's duration to cover it.
Centralized here so no call site can forget it — closed a bug found twice where a
duration meant for one servo silently got applied to the other's next move.

**Dispatch-time** (`loop()`): an independent, real-wall-clock check
(`top_dispatch_ms_`/`bottom_dispatch_ms_`) right before firing a step — verifies the
*other* servo's last dispatched step should actually be done by now. Mirrors CUBOTino's
`b_servo_operable`/`b_servo_stopped` flags, but checked live instead of pre-baked into a
duration. Exists so a bug in the plan-time math, or a future call site that bypasses
`append_step_()`, can't turn into a physical collision — normal operation should never
trip it.

Both layers must stay in the same (scaled-by-`speed_mul_`) unit system; a past bug had
the plan-time bookkeeping recording the unscaled value while the pushed step used the
scaled one, silently under-protecting whenever the multiplier wasn't exactly 1.0.

## Why blocking delays aren't the answer

CUBOTino's blocking `sleep_ms()` model gives a *structural* guarantee — the interpreter
is suspended, so overlap is impossible by construction, no bookkeeping required. This
project can't adopt that: the same ESP32 also holds the WiFi connection, the HA API
link, the camera pipeline, and the display, so blocking for the seconds a multi-step
sequence takes would risk exactly the kind of WiFi/API reliability problems documented
in `docs/robot.md`'s HA integration notes. The two-layer software guard above is the
trade-off for keeping the chip responsive to everything else it has to do.

## Settle pads at the scan-return boundary

Separate from the two timing layers above: the return-to-home sequence
(`advance_scan()`'s `scan_face_idx_ >= NUM_FACES` branch) also has two short
same-position dwell steps bracketing it — one before the first flip, one after the
last. These aren't cross-servo guards; they're plain settle margin at a boundary that's
had observed jamming — the O-face close step just before, and the final flip's own
declared duration, are both calibrated-duration estimates same as everywhere else, not
physical confirmation. The pre-pad is sized to also let the `HOMING` beep finish before
the real (loud) flip motion starts.

## What actually caused the R1/L1 jams

Not a timing race at all — the bottom servo's CCW spin was under-rotating, most likely
a servo horn slipping a tooth on the spline (a repeat failure — see `docs/servo-tuning.md`
"Confirmed findings" for the full history and current value). Fixed via `"Bottom: CCW
Pos"`. If it keeps drifting further, re-seat the horn rather than keep compensating in
software.

**Related open gap**: `Cubotino_settings.txt` keeps CW/CCW release-delta and
home-overshoot as four separate parameters, allowing per-direction asymmetry. This port
shares one pair across both directions — not changed since moving CCW Pos alone was
enough, but worth splitting if asymmetric tuning is needed again.

## The limitation nothing here fixes

Neither project has real position feedback — no limit switches, no encoders. Every
layer described above can only catch misattributed or underestimated *timing*. None of
it can detect a servo that's mechanically stalled and never reaches its target — which
is exactly what the CCW issue was, caught only because a human noticed the physical
symptom, not because any software guard flagged it. Closing that gap for real needs
position-feedback hardware.

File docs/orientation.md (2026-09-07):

# Cube Orientation & Camera Convention

## Loading Position

The user loads the cube in a fixed orientation before each scan:

```
White on top (U), Green facing robot front (F), Orange on left (L), Red on right (R)
Blue on back (B), Yellow on bottom (D)
```

## Camera

Top-down, fixed to the chassis — the cube moves (via Flip/Spin), the camera does not.
Since the arm returns to the same closed position for every capture, the camera's frame
is identical for all six scans.

```
image direction   →   physical robot direction
image TOP         =   whatever is currently FRONT
image BOTTOM      =   whatever is currently BACK
image LEFT        =   whatever is currently RIGHT   ← inverted mount
image RIGHT       =   whatever is currently LEFT
```

## Scan Sequence

Six positions, 0-indexed, matching `scan_face_idx_` in `rubiks_solver.cpp` and
`SCAN_SEQUENCE` in `const.py` (one shared list for both the manual button and the robot
service schema). The HA status sensor is 1-indexed (`"SCAN " + (scan_face_idx_ + 1)`).

**Flip**: Front→Bottom, Top→Front, Back→Top, Bottom→Back. Left/Right unchanged. (The
physical push that produces this — a lever swinging up through the turntable to tip the
cube forward — is described in `docs/robot.md` "Physical Mechanism".)
**Spin CW** (viewed from above): Front→Right→Back→Left→Front. Top/Bottom unchanged.

| Pos | Face (Top) | Front | Back | Left | Right | Motion from previous |
|-----|---|---|---|---|---|---|
| 0 | W | Green  | Blue | Orange | Red | load |
| 1 | B | White  | Yellow | Orange | Red | flip |
| 2 | Y | Blue | Green  | Orange | Red | flip |
| 3 | G | Yellow | White  | Orange | Red | flip |
| 4 | R | Green  | Blue | White  | Yellow | spin CW + flip |
| 5 | O | Blue | Green  | White  | Yellow | flip + flip |

Positions 0–3 are a barrel roll (Left/Right untouched). Position 4 adds a turntable
spin before its flip; position 5 is two more plain flips.

Red/Orange at positions 4/5 is a documented visual-confusion pair on this camera (see
`REFERENCE_LAB` in `camera_processor.py`) — this order was derived from first-principles
state tracing, not by eye, and should not be re-flipped without an objective check (e.g.
comparing a logged LAB reading against `REFERENCE_LAB["R"]` vs `["O"]` distance).

## Per-Face Raw Camera Orientation

Derived from the table above via `image-top=Front`, `image-left=Right`,
`image-bottom=Back`, `image-right=Left`:

| Face | Image TOP | Image LEFT | Image RIGHT | Image BOTTOM |
|---|---|---|---|---|
| W | G | R | O | B |
| B | W | R | O | Y |
| Y | B | R | O | G |
| G | Y | R | O | W |
| R | G | Y | W | B |
| O | B | Y | W | G |

Faces 0–3 share the same left/right adjacency (Orange/Red fixed through the barrel
roll). Faces 4–5 differ because the cube was spun 90° before the flip.

## Kociemba Face Mapping

Independent of the scan-order question — purely kociemba's own convention crossed with
solved-cube geometry.

**Kociemba order (`U R F D L B`) in colours: `W R G Y O B`**

```
   W
O  G  R  B
   Y
```

| Colour | Kociemba face | Canonical top | Canonical left |
|---|---|---|---|
| W | U | B | O |
| R | R | W | G |
| G | F | W | O |
| Y | D | G | O |
| O | L | W | B |
| B | B | W | R |

## Rotation Required per Face (raw → kociemba order)

| Face | Raw top | Kociemba top | Raw left | Kociemba left | Rotation needed |
|---|---|---|---|---|---|
| W | G | B | R | O | 180° |
| B | W | W ✓ | R | R ✓ | identity |
| Y | B | G | R | O | 180° |
| G | Y | W | R | O | 180° |
| R | G | W | Y | G | 90° CCW |
| O | B | W | Y | B | 90° CCW |

Matches deployed `FACE_SCAN_ROTATIONS` — a good independent check.

## Code Implementation

`FACE_SCAN_ROTATIONS` (`camera_processor.py`) rotates the cropped image before sticker
detection — the only orientation-correction layer (PIL: positive = CCW):

```python
FACE_SCAN_ROTATIONS: dict[str, float] = {
    "W":  180,
    "B":    0,
    "Y":  180,
    "G":  180,
    "O":   90,
    "R":   90,
}
```

`ROBOT_CAMERA_TO_KOCIEMBA_REMAP` (`solver.py`) is identity for all six faces — rotation
alone handles it, no index permutation needed.

## Original CUBOTino Reference

Flip/Spin definitions match CUBOTino's `Cubotino_moves.py`, written here as continuous
cycles:

- **Flip** (front→bottom): F→D→B→U→F
- **Spin CW**: F→R→B→L→F
- **Spin CCW**: F→L→B→R→F

Original CUBOTino scanned via a separate PC webcam; this project scans on the ESP32-CAM
itself. Starting orientation: CUBOTino's "Front facing viewer, Upper up" = this
project's Green-front, White-up.

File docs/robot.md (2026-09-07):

# Rubiks Robot — Architecture & Design

## Overview

```
┌─────────────────────────────────┐     ┌──────────────────────────────────────┐
│   Home Assistant (HA)           │     │   ESP32-S3 (ESPHome)                 │
│                                 │     │                                      │
│  custom_components/rubiks/      │◄───►│  esp32_camera  (OV2640)              │
│  ├─ camera_processor.py         │     │  light         (LED ring)            │
│  ├─ solver.py (kociemba)        │     │  components/rubiks_solver/           │
│  └─ button.py / sensor.py       │     │  ├─ top servo  (flipper arm)         │
│                                 │     │  ├─ bottom servo (rotating base)     │
│                                 │     │  ├─ TM1638 display (status/buttons)  │
│                                 │     │  └─ buzzer (audio feedback)          │
└─────────────────────────────────┘     └──────────────────────────────────────┘
```

One ESP32-S3 handles camera, LED, and both servos. HA handles colour detection and
solving. The two sides coordinate over the ESPHome native API via typed actions/events,
not entity-state polling.

---

## Hardware

| Block | Pins |
|---|---|
| OV2640 camera | GPIO 6-13, 15-18 (data/clock/sync), I2C on 4/5 |
| LED (LEDC ch 0) | GPIO 3 |
| Top servo (LEDC ch 2) | GPIO 1 |
| Bottom servo (LEDC ch 4) | GPIO 43 |
| TM1638 (STB/CLK/DIO) | GPIO 14 / 41 / 42 |
| Buzzer, RTTTL (LEDC ch 6) | GPIO 44 |

UART logging sacrificed for the servo pins — USB-JTAG logger used instead
(`logger: baud_rate: 0`).

**TM1638 DIO (GPIO42) briefly looked dead but wasn't** — the display worked on a
second, otherwise identical board but not on this one, even wired directly with test
jumpers (harness ruled out) and on a completely different DIO pin (GPIO47, also
ruled out). A raw `switch: platform: gpio` toggle test (bypassing the TM1638 driver
entirely) eventually found the real cause: a stray wire in the harness shorting the
DIO line to ground. Repeatedly driving a GPIO output into that short is the likely
reason it looked electrically dead under earlier testing. Once the short was
resolved and the harness resoldered, GPIO42 tested fine again and was kept as DIO.
GPIO47 and GPIO46 were also confirmed working during this process and are kept as
spares; GPIO46 is an ESP32-S3 strapping pin (selects ROM print verbosity at boot) so
it's a lower-priority spare. GPIO48 gave no response on this board — likely reserved
for an onboard RGB LED on this board family.

**LEDC timer pairing matters**: ch0+1 share timer0, ch2+3 timer1, ch4+5 timer2, ch6+7
timer3 on ESP32-S3. Two different-frequency outputs sharing a timer pair silently break
one of them — this is why the buzzer is on ch6, not ch5 (which shares a timer with the
bottom servo on ch4). The camera uses its own internal LEDC timer for XCLK, not a user
channel.

**Servos**: standard 50Hz, extended pulse range 0.5-2.5ms (not the standard 1-2ms — these
units only just reached ~180° at standard range). `auto_detach_time: 5s` on both
(must exceed the longest step duration to avoid mid-travel dropout).

**Power**: servos need an external 5V/1A+ supply, not ESP32-S3 GPIO. Decoupling
capacitors recommended at (in priority order): the 5V branch point, near the servo
connectors, and the ESP32's 3V3/GND pins if reboots occur during active WiFi TX.

**Framework: `arduino`, not `esp-idf`** (`esp32: framework:` in `rubiks-solver.yaml`) —
inherited unexamined from the original CUBOTino camera template
(`esp32-s3-cam-rubiks.yaml`), not a deliberate choice. `esp-idf` is arguably the better
fit for a camera+PSRAM ESP32-S3 project — Arduino is itself built as a component on top
of ESP-IDF, so it adds a compatibility-layer memory overhead on top, and the OV2640
`esp32_camera` driver has a known track record of being less stable under Arduino than
native IDF (more prone to init failures and heap fragmentation under memory pressure).
Not worth switching right now though: plenty of headroom on the current build (~37%
RAM, ~53% flash used), no camera stability issues actually observed, and a framework
switch is a real behavioral change (GPIO/LEDC timing can shift subtly) that would need
re-verifying camera, servo timing, and WiFi stability all over again. Revisit only if
something concrete comes up that `esp-idf` would specifically fix — camera crashes,
memory pressure, WiFi drops under load.

**Physical mechanism**: adapted from [CUBOTino](https://www.instructables.com/CUBOTino-Autonomous-Small-3D-Printed-Rubiks-Cube-R/)
(Andrea Favero). Key adaptations: ESP32-S3+OV2640 replaces Raspberry Pi+Pi Camera and a
separate MicroPython servo controller (one device instead of two); HA dashboard
entities replace the PC GUI for calibration; a non-blocking step queue replaces blocking
`sleep_ms()` execution (see `docs/collision-prevention.md` for why, and what that
trade-off costs).

---

## Physical Mechanism

Two moving assemblies, one servo each:

- **Top servo** drives what functions as two different things depending on where it's
  positioned in its swing: a **cover** that drops down from above (Close position,
  clamping the top two layers still against the frame) or lifts clear (Open), and a
  separate, smaller **flip lever** that swings up *from below* — passing through slots
  in the turntable — to reach the cube (Flip position). At Open, both are out of the
  way at once: the cover is raised clear above, and the flip lever sits retracted
  *below* the turntable, not poking through it — which is exactly why Open is the only
  position the turntable can safely spin freely in.
- **Bottom servo** drives the **turntable**, which holds the cube at all times and
  rotates to three meaningful angles: Home (centre) and ~90° CW/CCW either side.

How the three primitives below actually happen:
- **Rotate** — cover drops to Close, clamping the top two layers; turntable spins.
  Since the top two layers are held still, only the bottom layer actually turns
  relative to them — this is the only way this 2-servo design turns a single layer.
- **Spin** — cover lifts to Open (nothing touching the cube); turntable spins. With
  nothing clamped, the whole cube turns together as one block instead.
- **Flip** — turntable stays completely still, holding the cube; the flip lever swings
  up through the turntable's slots and pushes upward on the cube's back-bottom edge,
  tipping it forward over its front-bottom edge like tipping a box — front face ends
  up on the bottom (see `docs/orientation.md` for the full before/after mapping).

**Both the cover *and* the flip lever need the turntable at one of its three aligned
angles to do their job safely** — the cover because it clamps down around the cube
sitting in the turntable, the flip lever because it has to physically pass through the
turntable's slots to reach underneath. A turntable caught between slots would jam
either motion, not just a rotate. See `docs/collision-prevention.md` for the timing
guards this requires.

## Robot Primitives

| Token | Meaning | Top servo | Bottom servo |
|---|---|---|---|
| `F<n>` | Flip cube n times (front → bottom) | Flip (turntable-safe, same as Open) | Stationary |
| `S<1\|3>` | Spin full cube CW(1)/CCW(3) 90° | Open | Moves |
| `R<1\|3>` | Rotate bottom layer CW(1)/CCW(3) 90° | Closed (constrains top 2 layers) | Moves |

Example: `F1R1S3` = 1 flip, 1 CW bottom-layer rotation, 1 CCW full-cube spin. Cover must
be closed before `R` and open before `S`/`F` — the planners manage this automatically.
Correct *ordering* isn't sufficient on its own though; see
`docs/collision-prevention.md` for the timing guards needed on top of it.

---

## Starting Orientation

User places the cube: **White up, Green facing the camera (front)**. Maps directly to
kociemba's face assignment in `solver.py`: `W=U, Y=D, G=F, B=B, O=L, R=R`. Matches
CUBOTino's own default starting orientation — no remapping needed since the user always
loads the cube this way before the robot takes over, and the robot always returns it to
this exact orientation after scanning, before solving.

---

## Scan Flow

```
User places cube (White up, Green front)
  → HA calls esphome.rubiks_solver_start_scan
  → Robot moves to face 1, fires esphome.rubiks_face_ready {face}
  → HA automation: rubiks.robot_scan_face {face} (illuminate→capture→detect→store,
    calibrates after face 6) → esphome.rubiks_solver_face_scan_done
  → repeat ×6, then robot returns cube to White-up/Green-front,
    fires esphome.rubiks_scan_complete
  → HA automation: kociemba solve → esphome.rubiks_solver_execute_solution
  → Robot executes, fires esphome.rubiks_solve_done
```

Camera is top-down; cube loaded White=top, Green=front.

| Step | Face | Robot moves | kociemba face |
|---|---|---|---|
| 0 | White | (none) → close arm | U |
| 1 | Blue | open → 1 flip → close | B |
| 2 | Yellow | open → 1 flip → close | D |
| 3 | Green | open → 1 flip → close | F |
| 4 | Red | open → spin CW → 1 flip → close | R |
| 5 | Orange | open → 2 flips → close | L |
| — | Return | flip → spin_home → flip | — |

`SCAN_FACES[] = {"W","B","Y","G","R","O"}` in `rubiks_solver.cpp`, matching
`SCAN_SEQUENCE` in `const.py` — one shared list for both the manual scan button and the
robot service schema. The arm closes for every scan (camera is arm-mounted, closed arm
forms the light hood); `plan_top_cover_` isn't reset between faces so each flip planner
sees the correct carried-over state.

The return sequence deliberately avoids `rotate` — a `rotate`-based return would twist
the bottom layer 90° *after* the kociemba string was already computed from the scan,
leaving the cube one quarter-turn off from what the solution assumes. `flip → spin_home
→ flip` reaches White-up/Green-front with the turntable at home using only whole-cube
moves, verified step by step:
```
start:               U=O,F=Bl,D=Rd,Bk=G,L=W,R=Y   (turntable CW)
flip:                U=G,F=O,D=Bl,Bk=Rd            (L,R unchanged: W,Y)
spin_home(CW→HOME):  U=G,F=Y,D=Bl,Bk=W             (L,R now: O,Rd)   turntable HOME
flip:                U=W,F=G,D=Y,Bk=Bl             (L,R unchanged: O,Rd)  ← target ✓
```

kociemba string assembly (URFDLB order): `U=scan[0], R=scan[4], F=scan[3], D=scan[2],
L=scan[5], B=scan[1]`. Because the robot controls all cube movement during scanning,
`override_centre` in `detect_face_colors()` is always set from the robot's declared
face — never from classifying the centre square.

---

## Solve Flow

```
HA: kociemba solution string "U2 R1 F3 D2 ..."
  → esphome.rubiks_solver_execute_solution {solution}
  → robot_required_moves() (moves.h, C++ port of Cubotino_moves.py):
      adapt_move() maps abstract face → current physical position
      MOVES_TABLE lookup → robot primitive string
      cube_orient_update() tracks orientation change
      optimize_moves() strips cancelling S1/S3 pairs
  → plan_solution_() builds the full ServoStep queue
  → loop() drains it non-blocking
  → fires esphome.rubiks_solve_done, returns to IDLE
```

---

## HA ↔ ESP32 Interface

Typed ESPHome API actions/events, not entity-state polling.

**Actions** (`api: actions:` in `rubiks-solver.yaml`, appear in HA as
`esphome.rubiks_solver_<action>`): `start_scan`, `face_scan_done`, `execute_solution`
(`supports_response: optional`, returns `{accepted, move_count}` via `api.respond`),
`stop`, `confirm_safe_and_home`.

**Events** (fired from C++ via `fire_homeassistant_event()`, requires the component to
inherit `api::CustomAPIDevice` and `homeassistant_services: true` in YAML):
`esphome.rubiks_face_ready {face}`, `esphome.rubiks_scan_complete`,
`esphome.rubiks_solve_done`.

```cpp
class RubiksSolverComponent : public Component, public api::CustomAPIDevice { ... };
this->fire_homeassistant_event("esphome.rubiks_face_ready", {{"face", "G"}});
```

### The robot bridge (`custom_components/rubiks/robot_bridge.py`)

Was previously a separate `ha_automations/rubiks_robot.yaml` the user had to copy into
their own config (and edit if they renamed the ESPHome device) — moved into the
integration itself so installing via HACS is enough on its own, and a future fix here
reaches everyone on update rather than only people who re-copy the file. The ESPHome
device name became a config option (`ESPHOME_DEVICE_NAME`, default `rubiks_solver`)
instead of being hardcoded per-file, since it's the only place `esphome.<device>_*`
service names get built.

`async_setup_robot_bridge()` registers one `hass.bus.async_listen()` per event, torn
down automatically via `entry.async_on_unload()`:

1. **Scan coordinator** — `esphome.rubiks_face_ready` → 300ms settle delay →
   `rubiks.robot_scan_face {face}` → `esphome.<device>_face_scan_done`. Guarded by an
   `asyncio.Lock` so an overlapping event is silently dropped rather than run
   concurrently (mirrors the old automation's `mode: single` / `max_exceeded: silent`).
2. **Solve dispatcher** — `esphome.rubiks_scan_complete` → 1500ms settle delay → LED
   off → `rubiks.solve` (response) → `esphome.<device>_execute_solution`. Same
   single-at-a-time guard as above.
3. **Solve-done notification** — `esphome.rubiks_solve_done` → LED off (safety net for
   a directly-triggered solve with no preceding scan) → log.
4. **Robot Start Scan** — `rubiks_robot_start_requested` → `esphome.<device>_start_scan`.
5. **Robot Stop** — `rubiks_robot_stop_requested` → `esphome.<device>_stop`.
6. **Robot Advance Face** — `rubiks_robot_advance_face_requested` → `esphome.<device>_face_scan_done`.
7. **Scramble** — `rubiks_scramble_requested {solution}` → `esphome.<device>_execute_solution`
   (same pipeline/guards as a real solve).

The LED turned off in steps 2/3 is always the onboard ESP32-S3-CAM flash LED
(`light.<device>_flash_led`, same device-name prefix as the actions above) — not the
separately-configurable LED Entity ID option, which is for the illumination light used
during scanning and may point elsewhere.

The `solver_status` text sensor drives the TM1638 display and RTTTL beeps for dashboard
feedback but plays no role in control flow — that's actions/events only.

---

## HA Component Integration

### What `ScanFaceButton` does (Phase 1/2, manual)

Looks up the current face via `SCAN_SEQUENCE[len(scanned_faces)]`, illuminates + captures
+ detects (with `override_centre` always set from the sequence position, never from
classification), stores it, and after face 6 runs `_async_run_calibration()`. Kept
intact alongside the robot path — useful for debugging camera crop/calibration without
hardware, and shares the same `scanned_faces` store and calibration logic (not in
conflict if not run simultaneously with a robot scan).

### `rubiks.robot_scan_face` service

Accepts `{face}`, schema-validated against `SCAN_SEQUENCE` — there is only one such
list, used both as the manual button's lookup key and the robot service's schema.
Handler in `button.py` (`async_handle_robot_scan_face`), registered in `__init__.py`.
Runs the same illuminate→capture→detect→store pipeline as `ScanFaceButton` but with the
face label supplied directly. After face 6, calibrates with
`remap=ROBOT_CAMERA_TO_KOCIEMBA_REMAP`.

### `ROBOT_CAMERA_TO_KOCIEMBA_REMAP`

Kept as identity for all six faces — rotation via `FACE_SCAN_ROTATIONS`
(`camera_processor.py`) happens *before* detection instead of an index-permutation remap
applied after. See `docs/orientation.md` for the full derivation.

---

## ESPHome Component Design

```
esphome/
  rubiks-solver.yaml              ← device config (camera, LED, servos, component ref)
  components/rubiks_solver/
    __init__.py                   ← YAML schema, defaults, codegen
    moves.h                       ← C++ port of Cubotino_moves.py (pure logic)
    rubiks_solver.h               ← component class, ServoStep type, state enums
    rubiks_solver.cpp             ← primitive builders, planner, loop() drainer
```

**Kociemba runs in HA, not the ESP32** — the two-phase pruning tables need 10-20MB RAM;
the ESP32-S3 has 8MB PSRAM. HA already assembles the cube state string, so
`solver.solve()` is one more line in `solver.py`. The ESP32 only needs to faithfully
execute the solution string — it never needs to understand the cube.

**Why a C++ component, not YAML lambdas**: the servo logic
(`Cubotino_servos.py`, ~900 lines) has real state — 16 position/timing settings,
multi-step primitives with conditional branching, orientation tracking across a full
move sequence. YAML lambdas can't share state cleanly; C++ classes/enums/arrays map much
more directly to the Python source.

### Key types

```cpp
enum class TopCover { OPEN, CLOSED, FLIP };
// Bottom servo position is tracked by three plan-time booleans
// (plan_b_home_, plan_b_cw_pos_, plan_b_ccw_pos_), not an enum.

struct ServoStep {
    enum Target { TOP, BOTTOM } target;
    float    position;      // ESPHome normalised -1.0..1.0
    uint32_t duration_ms;   // wait after the PREVIOUS step fires before issuing this one
};
```

### Step queue pattern

All steps for a scan or solve are pre-planned into a `std::vector<ServoStep>` before
execution begins; orientation and cover state update *as steps are planned*, not during
execution — this keeps conditional logic ("if cover is already closed, skip") at plan
time where it's easy to reason about, and keeps `loop()` itself trivial: check the timer,
fire the next step.

`loop()` runs every ~16ms and must never block — `sleep_ms()` throughout the MicroPython
source becomes timer checks here, using `App.get_loop_component_start_time()` (cached
per tick) rather than `millis()`. `step_start_ms_ = 0` when execution begins makes step 0
fire immediately regardless of its own `duration_ms` — travel time belongs on step 1, not
step 0. The component calls `disable_loop()` whenever idle (`IDLE`/`SCAN_WAIT`) so it's
removed from the active loop entirely, re-entering via `enable_loop()` when a scan/solve
starts.

**Not using `transition_length`**: ESPHome's servo component has a smoothing option, but
it snaps to idle at full speed on the first call after reboot and gives no completion
callback — explicit step durations in the queue give the timing control this robot needs.

### Safety and timing

Full detail lives in dedicated docs rather than duplicated here:
- **Cross-servo collision prevention** (plan-time + dispatch-time timing guards, why
  blocking delays aren't viable here): `docs/collision-prevention.md`.
- **Unclean-reset boot gate + `needs_confirm_before_move_`**: on a crash/brownout/
  watchdog reset, `setup()` skips the auto-home glide, shows `CHK ARM`, and requires
  `confirm_safe_and_home()` before any move — same requirement now applies after
  `stop()` interrupts anything non-`IDLE`. See `docs/features.md` "Safety / state
  machine".

### Servo settings conversion

`Cubotino_settings.txt` stores raw MicroPython PWM duty (0-1023 at 50Hz).
`duty_to_esphome()` converts to ESPHome's -1.0..1.0:

```cpp
static float duty_to_esphome(int duty) {
    float pct = duty / 1023.0f * 100.0f;
    return (pct - 7.5f) / 5.0f;   // -1.0..1.0 for 2.5%..12.5%, idle=7.5%
}
```

`__init__.py` only handles schema validation and codegen — all position arithmetic is
in C++.

**Bottom CCW position has needed recalibrating multiple times** — likely the servo horn
slipping a tooth on the spline, not a software issue. Current value and full history:
`docs/servo-tuning.md` ("Confirmed findings" / "Current values") — treat that doc, not
this one, as the source of truth for calibration numbers so they don't go stale in two
places.

---

## ESPHome Build Gotchas

| Symptom | Cause | Fix |
|---|---|-----|
| `'APIServer' has no member 'send_homeassistant_event'` | Removed in ESPHome 2026.x | Inherit `api::CustomAPIDevice`, call `this->fire_homeassistant_event()` |
| `fire_homeassistant_event() requires 'homeassistant_services: true'` | Guard disabled at compile time | Add `homeassistant_services: true` under `api:` |
| `text_sensor.h: No such file or directory` | `text_sensor` in `DEPENDENCIES` but sources not compiled | Use `AUTO_LOAD = ["text_sensor"]` instead |
| `Component rubiks_solver requires component text_sensor` | Same as above, `DEPENDENCIES` needs a user-facing config block | Same fix |
| `[on_state] is an invalid option` | ESPHome text sensors use `on_value` | Replace `on_state:` with `on_value:` |
| `cv.positive_time_period_milliseconds` validation error | Expects `"900ms"` strings, not raw ints | Use `cv.positive_int` for raw ms values into `uint32_t` members |

`DEPENDENCIES` requires the user to explicitly configure that component in their own
YAML; `AUTO_LOAD` pulls in a component's sources programmatically without that
requirement — use `AUTO_LOAD` for anything the custom component creates itself (e.g. a
text sensor via `text_sensor.new_text_sensor()` in `to_code()`).

---

## Source Reference Files

`CUBOTino_Files/ESP32_files/` (gitignored, drop files here manually).

| File | Role | Ported to |
|---|---|---|
| `Cubotino_moves.py` | kociemba → robot move string; orientation tracking | `moves.h` |
| `Cubotino_servos.py` | servo primitives + execution loop | `rubiks_solver.cpp` |
| `Cubotino_settings.txt` | 16 servo position/timing defaults | C++ constants + `duty_to_esphome()` |
| `esp32-s3-cam-rubiks.yaml` | Camera ESPHome config (starting point) | `rubiks-solver.yaml` camera section |
| `main.py` | MicroPython orchestration via UART | Replaced by HA automations |
| `servo_to_mid.py` | Assembly servo-centering utility | `sweep_top_servo`/`sweep_bottom_servo` scripts |

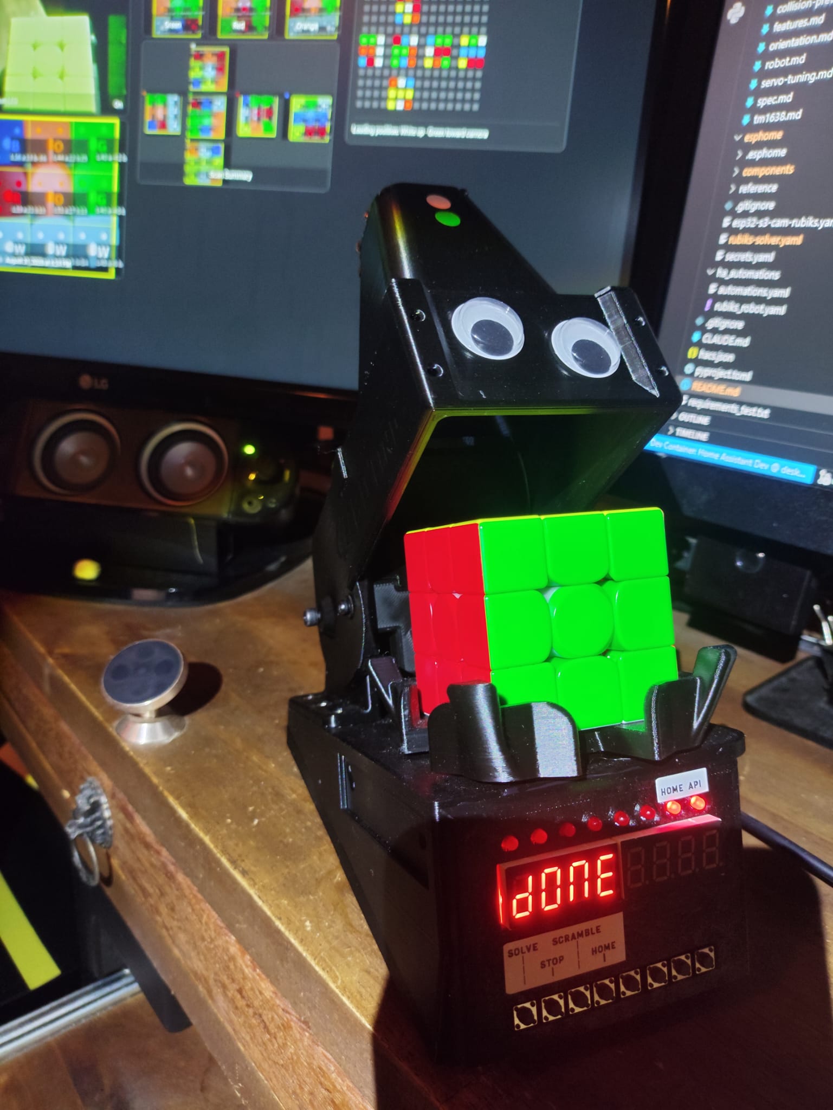
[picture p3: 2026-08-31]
docs/Images/Esp_cam/Rubee.jpeg

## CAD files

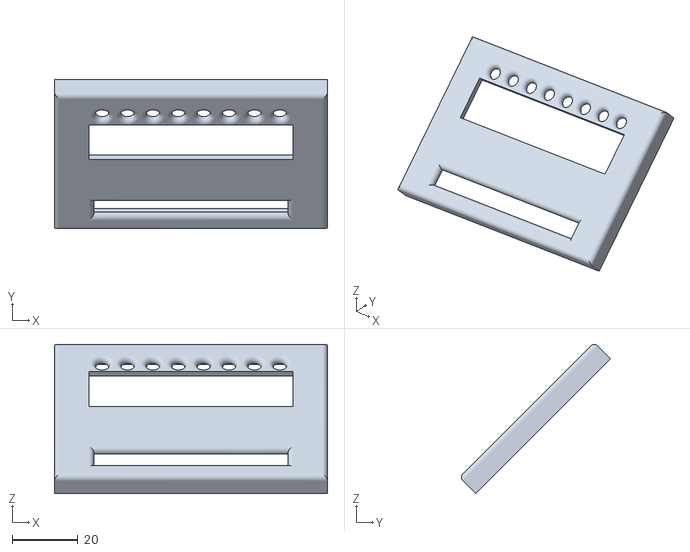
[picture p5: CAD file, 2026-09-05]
3d_prints/TM1638 Cover.stl
83.0 x 45.3 x 45.3

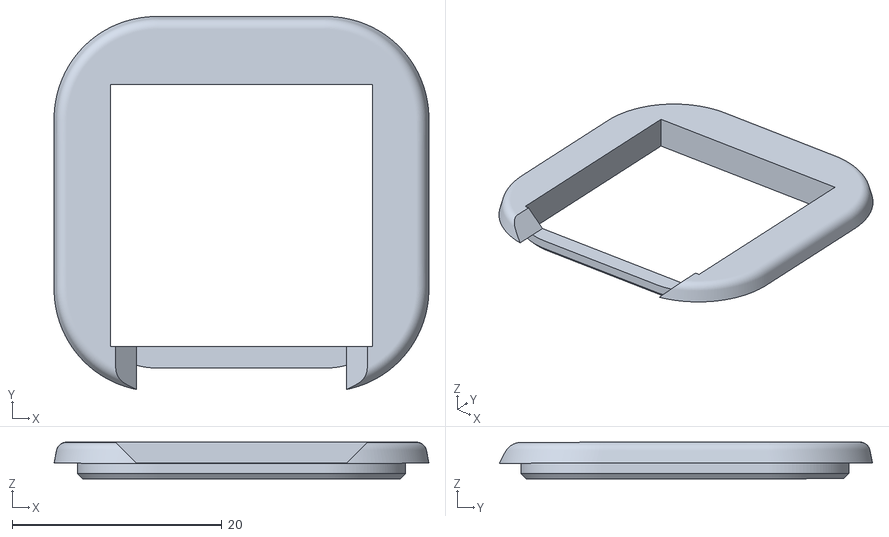
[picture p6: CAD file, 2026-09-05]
3d_prints/Camera Holder.stl
35.8 x 35.6 x 3.53

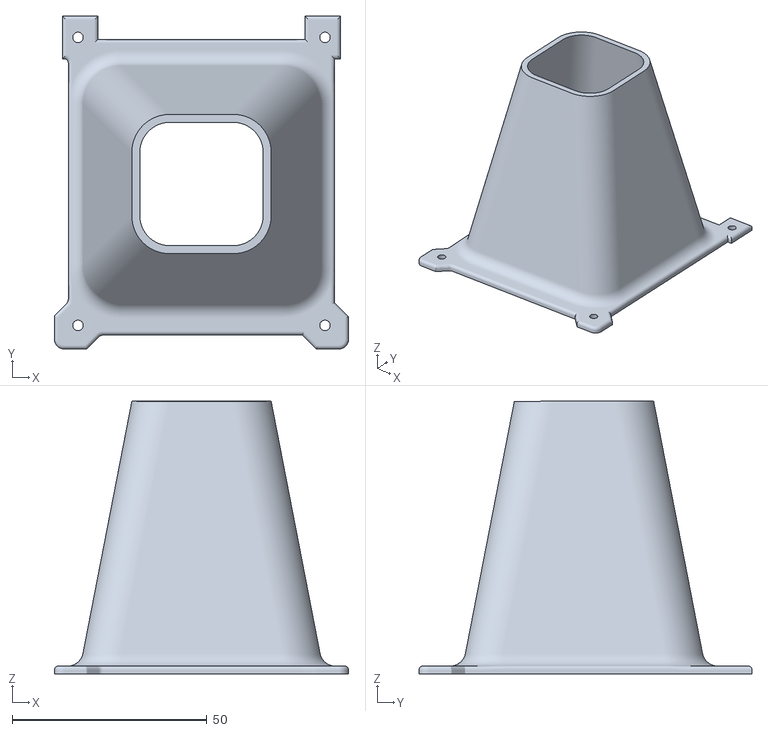
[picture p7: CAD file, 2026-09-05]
3d_prints/Camera Hood.stl
75.5 x 85.5 x 70.0

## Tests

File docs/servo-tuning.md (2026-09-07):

# Servo Tuning Reference

Practical companion to `docs/robot.md` and `docs/collision-prevention.md` — what each
calibration number actually controls, how to diagnose a bad value, and the current
tuning state. Update the table below as values change; this doc is meant to stay a
living reference, not a changelog (see `docs/archive/` for session history).

## Diagnostic method

Worked reliably across every servo issue found this session, in this order:

1. **Isolate with the narrowest test button that reproduces it** — a single-leg test
   (`test_rotate_cw_home()`, `test_spin_ccw_home()`, etc.) before a composite move
   (`D1`, `U1`...) before a full scan. Composite moves make it hard to tell which
   sub-step is actually at fault.
2. **Rule out time before position.** Push the relevant duration well above its current
   value and retest. If that fixes it, it was genuinely under-timed — dial back to find
   the minimum. If it makes *no* difference, time was never the bottleneck — stop
   touching durations and look at the target position instead.
3. **Rule out mechanical before software.** Physically check for play/slippage (the
   bottom servo horn has needed re-seating before — see `docs/robot.md`). If the
   mechanism is solid, the cause is a wrong number, not a wrong assumption about what
   "should" be enough time.
4. **Remember CW and CCW are asymmetric but often share one constant.** A value tuned
   against one direction's required distance isn't guaranteed to cover the other — see
   "Known gap" below. If one direction works and its mirror doesn't, check whether the
   shared constant simply needs to cover the *larger* of the two distances.
5. **Check whether the parameter you're tuning actually governs the thing you're
   observing.** More than one round of tuning here targeted the wrong number because it
   *sounded* related but didn't actually touch the observed symptom — see "Confirmed
   findings" below for two examples. Trace the actual code path
   (`plan_rotate_()`/`plan_spin_()` in `rubiks_solver.cpp`) before assuming a name
   implies function.

## Calibration entity glossary

Every entry cross-checked against the current `rubiks_solver.cpp`/`.h` and against
[Andrea Favero's own settings reference](../CUBOTino_Files/ESP32_files/Cubotino_settings.md)
(local copy, gitignored) — his **Default**/**AF** columns (Default = stock, AF = his own
tuned unit) are kept here for context when diffing behavior, not as numbers to copy onto
this build's different camera/servos. For what's actually live *here*, see "Current
values" below (points at the **Report: Servo Parameters** dashboard button, not a stale
hardcoded number) — this table is about completeness against the original, including the
handful of his parameters this port doesn't have an equivalent for.

### Top servo (flip lever) — positions

| HA entity | C++ member | Plain English | Original name | Default | AF |
|---|---|---|---|---|---|
| `Top: Flip Pos` | `d_t_flip_` → `t_flip_v_` | Same servo as Open/Close Pos below, but at this position it swings a separate, smaller flip lever up through the turntable's slots to tip the cube forward (front face → bottom) — see `docs/robot.md` "Physical Mechanism" | `t_servo_flip` | -0.9 | -0.9 |
| `Top: Open Pos` | `d_t_open_` → `t_open_v_` | The "rest"/idle position — cover raised clear above the cube, *and* the flip lever retracted below the turntable (not poking through it). Required before the turntable can spin freely | `t_servo_open` | -0.32 | -0.32 |
| `Top: Close Pos` | `d_t_close_` → `t_close_v_` | Lever lowered onto the cube, constraining the top two layers — required before a bottom-layer `Rotate` | `t_servo_close` | 0 | 0 |
| *not implemented* | — | Andrea's arm position for reading a face with an arm-mounted PiCamera. Not applicable here — this build uses a fixed top-mounted camera, so face capture doesn't depend on arm position | `t_servo_read` | -0.5 | -0.5 |

### Top servo — timings (ms, between the positions above)

| HA entity | C++ member | Plain English | Original name | Default | AF |
|---|---|---|---|---|---|
| `Top: Flip-Close` | `t_flip_to_close_time_` | Travel time, Flip position → Close position | `t_flip_to_close_time` | 600 | 380 |
| `Top: Close-Flip` | `t_close_to_flip_time_` | Travel time, Close position → Flip position (reverse direction, separate constant since geometry/gravity differ) | `t_close_to_flip_time` | 600 | 420 |
| `Top: Flip-Open` | `t_flip_open_time_` | Travel time between Flip and Open positions, either direction | `t_flip_open_time` | 500 | 340 |
| `Top: Open-Close` | `t_open_close_time_` | Travel time between Open and Close positions, either direction — the shortest top-servo move, since Open/Close sit close together (only Flip is the far extreme) | `t_open_close_time` | 300 | 100 |

### Top servo — release (currently inert)

| HA entity | C++ member | Plain English | Original name | Default | AF |
|---|---|---|---|---|---|
| `Top: Release Offset` (commented out in YAML) | `d_t_rel_offset_` → `t_rel_v_ = t_close_v_ - offset` | Small pull-back from Close to relieve clamping pressure on the cube — the top-servo equivalent of `Extra Sides` below | `t_servo_rel_delta` | 0.02 | 0.06 |
| *not implemented* | — | Time for the release pull-back above — no dedicated HA entity here, since Release Offset is disabled this reuses whichever cover-transition duration is already in play (see `solver()`'s docstring in `rubiks_solver.cpp`) | `t_rel_time` | 200ms | 0ms |

Release Offset sits at `0` (a no-op — `t_rel_v_` currently equals `t_close_v_` exactly)
since the entity was never uncommented — matches Andrea's own Default of `0` too, so this
isn't a regression, just an unfinished feature (see `docs/features.md`). Worth noting his
own AF-tuned value is `0` as well, for both the top *and* bottom release — see the
`Bottom: Release` row below.

### Bottom servo (turntable) — positions

| HA entity | C++ member | Plain English | Original name | Default | AF |
|---|---|---|---|---|---|
| `Bottom: CCW Pos` | `d_b_ccw_` → `b_ccw_v_` | Raw full ~90° CCW endpoint from home. Used directly as `Rotate`'s CCW target, and combined with `Extra Sides` to form `Spin`'s CCW resting point | `b_servo_CCW` | -1 | -1 |
| `Bottom: Home Pos` | `d_b_home_` → `b_home_v_` | Center/neutral resting position — the reference point everything else (CCW/CW Pos, Extra Home) is measured relative to | `b_home` | 0 | 0 |
| `Bottom: CW Pos` | `d_b_cw_` → `b_cw_v_` | Raw full ~90° CW endpoint from home, mirror of CCW Pos | `b_servo_CW` | 1 | 1 |
| `Bottom: Extra Sides` | `d_b_extra_sides_` | Delta subtracted (CW) / added (CCW) from CW/CCW Pos to get the **release** position (`b_cw_rel_v_`/`b_ccw_rel_v_`) — a small back-off from the raw extreme that relieves tension between cube, holder, and cover. Used as `Spin`'s actual resting point, and as `Rotate`-out's second (short) step. Andrea's original has separate CW/CCW values (`b_rel_CCW`/`B_rel_CW`); this port shares one across both — see "Known gap" below | `b_rel_CCW` / `B_rel_CW` | 0.04 / 0.04 | 0.06 / 0.06 |
| `Bottom: Extra Home` | `d_b_extra_home_` | Delta from Home Pos used for the **intermediate overshoot waypoint** in `Rotate`-*home*'s first step only. Does **not** affect the final resting position — that's always exactly `Home Pos` (see confirmed finding below). Same one-shared-value simplification as Extra Sides | `b_extra_home_CCW` / `b_extra_home_CW` | 0.12 / 0.12 | 0.1 / 0.1 |

### Bottom servo — timings (ms)

| HA entity | C++ member | Plain English | Original name | Default | AF |
|---|---|---|---|---|---|
| `Bottom: Spin` | `b_spin_time_` | Duration for every `plan_spin_()` move — whole-cube spin, cover open, both spin-out and spin-home | `b_spin_time` | 700 | 440 |
| `Bottom: Rotate` | `b_rotate_time_` | Duration for the **long** leg of every `plan_rotate_()` call — home→target on rotate-out, target→near-home on rotate-home. One shared value for both CW and CCW | `b_rotate_time` | 800 | 540 |
| `Bottom: Release` | `b_rel_time_` | Duration for the **short** leg of every `plan_rotate_()` call — the final few-unit settle to the exact resting position, both directions. This build needs far more than either of Andrea's values (~500ms vs his 0-200ms) — looks like servo/gear-train stiction rather than a bug, see the tuning log below | `b_rel_time` | 200 | 0 |

### Not tunable per-servo in this build

| Original name | Default | AF | Why not |
|---|---|---|---|
| `t_min_pulse_width` / `t_max_pulse_width` | 1 / 2 | 1 / 2 | Fixed in this build's ESPHome `servo:` config (`min_level`/`max_level`) for both servos, not an HA entity |
| `b_min_pulse_width` / `b_max_pulse_width` | 1 / 2 | 0.98 / 1.98 | Same — fixed in ESPHome config |
| `t_srv_pw_range` / `b_srv_pw_range` | 'small' / 'small' | 'small' / 'small' | Named pulse-width-range presets from Andrea's own calibration tooling. This build's ESPHome config states the range directly instead of picking a preset |

### Global

| HA entity | C++ member | Plain English |
|---|---|---|
| `Speed Multiplier` | `speed_mul_` | Scales every step's duration uniformly at plan time — applied last, after all other duration math including the cross-servo stretch in `append_step_()`. No original-project equivalent; added for this port. |

## Confirmed findings this session

- **`plan_rotate_()`'s two steps were swapped for a long time** (found via comparing
  against `Cubotino_servos.py`) — the real long traverse was getting `Bottom: Release`-
  scale time and vice versa. Fixed 2026-08-15. If you're referencing old notes/logs from
  before that date, the duration pairing described there is wrong.
- **`Bottom: Extra Home` does not affect the final rotate-home resting position** — only
  an intermediate waypoint on the way there. The actual final-approach bottleneck is
  `Bottom: Release`. Confirmed empirically: `Extra Home` swept 2→15 with zero visible
  change in the final position; `Bottom: Release` 100ms→500ms fixed it immediately.
- **`Bottom: CCW Pos` and `Bottom: CW Pos` both needed moving further from home than
  their original-project defaults** — likely the servo horn slipping a tooth on the
  spline (documented happening once before in `features.md`), confirmed *not* a current
  loose-horn issue by physical check as of this session.
- **`Bottom: Rotate` is shared across CW/CCW but the two directions need different
  amounts** — CCW's home-to-target distance is larger than CW's, so a value tuned
  against CW's out-leg may under-serve CCW's.
- **`Bottom: CCW Pos` moved twice** — 51→40→10, with the entity's `min_value` widened
  each time it got hit (now 5). Each move was confirmed against a real test, not
  guessed; if it needs to go further still, that's a stronger signal for re-seating the
  horn than for continuing to widen the floor.
- **`Bottom: CCW Pos` at 10 was silently clamped.** ESPHome's `Servo::write()` clamps
  every value to `[-1.0, 1.0]` before output. `CCW Pos=10` computed to -1.304 (out of
  range) — clamped to exactly -1.0, the same output as `Bottom: Extra Sides`' release
  position (also clamped, since 10+extra_sides still couldn't clear the boundary with
  extra_sides capped at 15). CCW rotate and CCW release were physically identical moves
  until this was found — a genuine bug in its own right. Tried `CCW Pos=28` (just
  inside range, restoring a real distinct release position) — didn't move the separate
  `Bottom: Release` timing-floor issue below, so **reverted back to 10** (see tuning
  log). The clamping bug itself is still real and could resurface if CCW Pos is ever
  lowered again for an unrelated reason — worth re-checking the computed value against
  ±1.0 whenever it changes.
- **The `Bottom: Release` floor (~500ms) is a genuine servo characteristic, not a
  bug.** Doubling `Extra Sides`/`Extra Home` (4→8, 2→4) and fixing the CCW clamp above
  both landed cleanly but didn't move the floor. Confirmed it's not distance-related
  either: CW was never clamped (always had a real, distinct release position) and
  still hits the same ~500ms floor as CCW. Points to a stiction/static-friction
  property of this servo's gear train — it needs sustained torque for a while before
  it actually turns, regardless of how far it's asked to travel. Physically inspected
  the bottom servo's gear train/horn (same spot as the earlier CCW Pos slip) — no
  fault found, so **500ms is accepted as this hardware's real floor**, not something
  left to keep chasing via tuning.
- **Scan flips did an unwanted extra reversal.** `plan_flip_()` always auto-opened the
  cover after the last flip unless a rotate immediately followed — during scanning the
  caller closes the cover again right after anyway, so every scan flip did
  FLIP→OPEN→CLOSE (two reversals) instead of FLIP→CLOSE. Looked like "the flip cuts
  short and goes back down." Fixed by adding a scan-only `next_token=='X'` sentinel to
  `plan_flip_()` that leaves the arm at FLIP for the caller's own
  `plan_ensure_cover_closed_()` to finish directly. Doesn't affect solve/scramble —
  `'X'` never appears in a real kociemba move string.
- **A redundant top "release" step was costing a full leg's duration for zero
  motion.** `plan_ensure_cover_closed_()` and `plan_flip_()`'s close-then-rotate branch
  both queued a second top-servo step at the release position — but with `Top: Release
  Offset` at its permanent `0`, that position is identical to Close, so the step never
  actually moved anything. Now skipped whenever the offset is `0` (i.e. always, until
  that feature is finished) — removes one full `Top: Open-Close`/`Top: Flip-Close`
  duration of dead time per bottom-layer turn, at zero cost.

## Current values

Numbers here go stale the moment anyone retunes a slider, so none are duplicated in
this doc anymore. To see what's actually live right now: press **Report: Servo
Parameters** on the dashboard, which calls `dump_config()` and logs every raw duty
setting, computed servo position, and timing value in one shot — read that log instead
of trusting any number written here. If you retune anything, also write the new value
back into the YAML's `initial_value` once confirmed, so a fresh flash doesn't regress
behind the dashboard.

## Tuning log

Running record of specific value changes while this is still being dialled in — newest
first. Once tuning settles down, this can be trimmed back to just the current values
note above; until then it's cheaper to log a change here than to lose track of why a
number is what it is.

- **2026-09-06** — YAML `initial_value`s synced to live dashboard state after the
  speed-up pass below: `Top: Flip-Close` 400→450, `Top: Close-Flip` 400→550,
  `Top: Open-Close` 300→**100** (matches Andrea's own AF-tuned value exactly),
  `Bottom: Home Pos` 77→76, `Bottom: Extra Sides` 4→8, `Bottom: Extra Home` 2→4,
  `Bottom: Release` 700→550, `Bottom: Spin` 700→400, `Bottom: Rotate` 700→500. Compiled
  clean; a fresh flash now boots straight into the currently-confirmed values.
- **2026-09-06** — `Top: Close-Flip` 400→**500ms**, `Top: Flip-Open` 300→**400ms**.
  Fixed scan flips cutting short (see "Confirmed findings" — the redundant-open-step
  bug had masked whether duration was ever the real problem; once that was fixed, a
  clean retest showed it was). Found via push-high-then-dial-back: tested 800/600ms
  first to confirm duration was the lever, then walked both down until they held.
- **2026-09-06** — `Bottom: CCW Pos` 10→28→**10 (reverted)**. Tried un-clamping the
  CCW release position (see "Confirmed findings"); didn't move the `Bottom: Release`
  timing floor, so reverted rather than keep the (small) reduction in CCW travel for
  no benefit.

## Believed-home safeguard

`binary_sensor.rubiks_solver_believed_home` — optimistic, derived from the commanded
move sequence (`plan_top_cover_`/`plan_b_home_`), not real position feedback. False the
instant any step is queued; recomputed true/false only when a sequence completes, based
on whether it ended at cover-open + bottom-home. `test_scan_cycle()` is the clearest
case where it goes false without anything being wrong — it deliberately parks at a scan
face, not home.

`start_scan()` and `execute_solution()` hard-block if this is false, same pattern as
`needs_confirm_before_move_` — refuse and require `confirm_safe_and_home()` first,
rather than silently assuming home like they used to.

## Known gap

CW/CCW share one `Bottom: Rotate` / `Bottom: Extra Sides` / `Bottom: Extra Home` value
each, rather than four independent per-direction parameters like
`Cubotino_settings.txt` (`b_rel_CCW`/`B_rel_CW`, `b_extra_home_CCW`/`b_extra_home_CW`).
Current approach is to tune the shared value to comfortably cover the *larger* of the
two directions' needs, accepting harmless slack on the smaller one. Splitting into
direction-specific pairs remains a possible future change if this stops being good
enough — see `docs/collision-prevention.md`.

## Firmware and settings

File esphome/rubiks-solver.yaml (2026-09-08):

esphome:
  name: rubiks-solver
  project:
    name: "okhammahko.rubiks_solver"
    version: "0.4.15"
  on_boot:
    then:
      - script.execute: show_boot_text

esp32:
  framework:
    type: arduino
  board: esp32-s3-devkitc-1 # Pinout: https://emakefun.github.io/emakefun-docsify/zh-cn/esp32/esp32s3-cam/picture/esp32s3_cam_pin.png

# Exposed: GPIO0, GPIO1, GPIO14, GPIO41, GPIO42, GPIO43, GPIO44, GPIO46, GPIO47, GPIO48

# +--------------+--------+----------------------------------+------------+
# | FUNCTION     | GPIO   | NOTES                            | STATUS     |
# +--------------+--------+----------------------------------+------------+
# | TM1638 STB   | GPIO14 | baseline                         | ✅ Working |
# | TM1638 CLK   | GPIO41 | debug pin                        | ✅ Working |
# | TM1638 DIO   | GPIO42 | harness short fixed, resoldered  | ✅ Working |
# | Top Servo    | GPIO1  | -                                | ✅ Working |
# | Bottom Servo | GPIO43 | -                                | ✅ Working |
# | Buzzer       | GPIO44 | -                                | ✅ Working |
# +--------------+--------+----------------------------------+------------+

# ── Spare pins (tested, unused) ──
# +--------+-------------------------------------------+---------------+
# | GPIO   | NOTES                                     | STATUS        |
# +--------+-------------------------------------------+---------------+
# | GPIO47 | tested end-to-end with TM1638, unused now | ✅ Spare      |
# | GPIO46 | strapping pin, spare only                 | ⚠️ Spare only |
# | GPIO48 |                                           | ?              |
# +--------+-------------------------------------------+---------------+

wifi:
  ssid: !secret wifi_ssid
  password: !secret wifi_password
  fast_connect: true
  power_save_mode: none
  manual_ip:
    static_ip: 192.168.1.143
    gateway: 192.168.1.1
    subnet: 255.255.255.0

ota:
  - platform: esphome

logger:
  baud_rate: 0 # disables UART logger output → no more serial noise on GPIO43

debug:

text_sensor:
  - platform: debug # Useful for any brownout debugging
    reset_reason:
      name: "Reset Reason"
      icon: mdi:restart-alert

psram:
  mode: octal

# ── TM1638 display ────────────────────────────────────────────────────────────
# 8-digit 7-segment display. Shows solver_status text sensor state.
display:
  platform: tm1638
  id: tm1638_display
  dio_pin: 42 # Green Wire  | Cable position 2
  clk_pin: 41 # Blue Wire   | Cable position 1
  stb_pin: 14 # Yellow Wire | Cable position 7
  intensity: 1
  update_interval: 500ms

  lambda: |-
    // Priority order: boot splash > connect confirmation > API lost > transient
    // message (rejected command / already-solved / HA-reported scan-solve error —
    // see show_transient_message() in rubiks_solver.h) > moves-left while solving >
    // plain status text (IDLE/LOAD, SCAN N, FACE Nc, HOMING, ...).
    std::string s;
    bool solving = id(solver_status_text).has_state() && id(solver_status_text).state == "SOLVING";
    if (id(g_show_boot)) {
      s = "RUBEE";
    } else if (id(g_show_ready)) {
      s = "READY";
    } else if (!global_api_server->is_connected()) {
      s = "LOST API";
    } else if (!id(solver).transient_message().empty()) {
      s = id(solver).transient_message();
    } else if (solving && id(moves_remaining).has_state()) {
      char buf[9];
      snprintf(buf, sizeof(buf), "LEFT%3d", (int) id(moves_remaining).state);
      s = buf;
    } else {
      std::string status = id(solver_status_text).has_state() ? id(solver_status_text).state : std::string("IDLE");
      // Prompt to place the cube once idle and confirmed home — "READY" is already
      // taken (post-connect confirmation), so this reuses the IDLE slot instead.
      s = (status == "IDLE" && id(believed_home).state) ? "LOAD" : status;
    }
    s.resize(8, ' ');  // right-pad — the TM1638 shows all 8 digits regardless
    it.print(s.c_str());
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

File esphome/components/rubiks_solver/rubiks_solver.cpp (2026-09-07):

#include "rubiks_solver.h"
#include "moves.h"
#include "esphome/core/log.h"
#include "esphome/core/application.h"
#include <algorithm>
#include <esp_system.h>

namespace esphome {
namespace rubiks_solver {

static const char *const TAG = "rubiks_solver";

// Reset reasons that indicate the previous session ended deliberately (fresh power-up,
// a requested restart such as OTA, an external reset button press, or a developer
// actively connected via SDIO/USB/JTAG) — i.e. the last commanded servo position, if
// any, is trustworthy. Anything else (panic, any watchdog, brownout, power glitch, CPU
// lockup, or an unrecognised reason) means the firmware could have been interrupted
// mid-motion, leaving the arm/turntable somewhere setup()'s boot glide doesn't expect —
// see setup()'s comment and confirm_safe_and_home().
static bool is_clean_reset_reason(esp_reset_reason_t reason) {
  switch (reason) {
    case ESP_RST_POWERON:
    case ESP_RST_SW:
    case ESP_RST_EXT:
    case ESP_RST_SDIO:
    case ESP_RST_USB:
    case ESP_RST_JTAG:
      return true;
    default:
      return false;
  }
}

// Face labels in scan order (White up, Green front starting position).
// Scan order: cube loaded White=top, Green=front; camera looks at top face.
// 0=W(start) 1=B(flip) 2=Y(flip) 3=G(flip) 4=R(spinCW+flip) 5=O(flip×2)
//
// R/O at positions 4/5 were flip-flopped twice on 2026-07-26 based on verbal "hardware
// confirmed" reads of the camera image — Red and Orange are a documented visual-confusion
// pair on this camera/lighting (see REFERENCE_LAB comment in camera_processor.py), and the
// two live tests that day gave contradictory answers. This value is instead derived
// mathematically from the stated Loading Position (W=U,G=F,O=L,Rd=R) and the Flip/Spin
// definitions in docs/orientation.md, tracing full (U,D,F,B,L,R) state through each step:
// position 4 = spin CW + flip → Top=Red; position 5 = flip×2 → Top=Orange. Every derived
// Front/Left/Right value at each step matches what was already independently agreed on,
// and both opposite-colour-pair validity and a spin-direction sanity check (CCW breaks the
// agreed Left=White/Right=Yellow fact at position 4, confirming CW is correct) support it.
// Do not re-flip this without an objective check (e.g. compare the raw LAB reading logged
// as "Centre colour overridden: detected X" against REFERENCE_LAB["R"] vs ["O"] distance) —
// eyeballing this pair on this camera has proven unreliable twice.
static const char *const SCAN_FACES[] = {"W", "B", "Y", "G", "R", "O"};
static const int NUM_FACES = 6;

// ── Duty → ESPHome conversion ─────────────────────────────────────────────────
// Extended pulse range: 0.5–2.5 ms at 50 Hz → 2.5%–12.5% duty.
// ESPHome maps: min_level (2.5%) → -1.0,  idle_level (7.5%) → 0.0,  max_level (12.5%) → +1.0.
// Formula: (pct - 7.5) / 5.0  →  maps 2.5%→-1, 7.5%→0, 12.5%→+1.
// Duty values are raw MicroPython 0–1023 scale from Cubotino_settings.txt.
// Absolute pulse widths are preserved — e.g. duty=76 still sends 1.49ms regardless of range.

float RubiksSolverComponent::duty_to_esphome(int duty) {
  float pct = duty / 1023.0f * 100.0f;   // 0-1023 → % duty cycle
  return (pct - 7.5f) / 5.0f;            // maps 2.5%→-1, 7.5%→0, 12.5%→+1
}

// ── Setup ──────────────────────────────────────────────────────────────────────

void RubiksSolverComponent::recompute_positions() {
  t_flip_v_          = duty_to_esphome(d_t_flip_);
  t_open_v_          = duty_to_esphome(d_t_open_);
  t_close_v_         = duty_to_esphome(d_t_close_);
  t_rel_v_           = duty_to_esphome(d_t_close_ - d_t_rel_offset_);

  b_ccw_v_           = duty_to_esphome(d_b_ccw_);
  b_home_v_          = duty_to_esphome(d_b_home_);
  b_cw_v_            = duty_to_esphome(d_b_cw_);
  b_ccw_rel_v_       = duty_to_esphome(d_b_ccw_ + d_b_extra_sides_);
  b_cw_rel_v_        = duty_to_esphome(d_b_cw_  - d_b_extra_sides_);
  b_home_from_cw_v_  = duty_to_esphome(d_b_home_ - d_b_extra_home_);
  b_home_from_ccw_v_ = duty_to_esphome(d_b_home_ + d_b_extra_home_);
}

void RubiksSolverComponent::setup() {
  recompute_positions();

  esp_reset_reason_t reason = esp_reset_reason();
  if (!is_clean_reset_reason(reason)) {
    // The previous session ended via crash/watchdog/brownout, not a deliberate reset —
    // the arm and turntable's actual physical position is unknown and may not match
    // what queue_boot_glide_() assumes (idle/home). Driving them blindly risks the
    // lifter jamming against the cube holder if the turntable isn't at one of its
    // slot-aligned positions (see docs/robot.md; investigated 2026-08-01). The servo
    // platform itself won't move anything on its own here — with `restore:` unset in
    // YAML, its own setup() just detaches (silences the PWM signal) rather than driving
    // to a position — so simply not queuing a move is enough to actually prevent motion.
    // Stay in IDLE and wait for a human to check before calling confirm_safe_and_home().
    ESP_LOGW(TAG, "Unclean previous reset (reason=%d) — skipping auto-home. Check the "
                  "arm/turntable aren't in a colliding position, then call "
                  "confirm_safe_and_home().", (int) reason);
    publish_status_("CHK ARM");
    state_ = SolverState::IDLE;
    needs_confirm_before_move_ = true;
    return;
  }

  queue_boot_glide_();
}

void RubiksSolverComponent::confirm_safe_and_home() {
  if (state_ != SolverState::IDLE) {
    ESP_LOGW(TAG, "confirm_safe_and_home ignored — not idle (state=%d)", (int) state_);
    return;
  }
  ESP_LOGI(TAG, "confirm_safe_and_home — proceeding to home");
  needs_confirm_before_move_ = false;
  queue_boot_glide_();
}

// Glide to rest position (cover open, bottom home) rather than snapping. Queues 10 top
// steps that sweep the cover from wherever it starts to open over ~1s, then settles the
// bottom to home. Shared by setup() (on a clean reset) and confirm_safe_and_home() (after
// an unclean one, once a human has confirmed it's safe). Uses SERVO_TEST so loop() drains
// the queue and returns to IDLE on its own.
void RubiksSolverComponent::queue_boot_glide_() {
  steps_.clear();
  const int N = 10;
  for (int i = 1; i <= N; i++)
    append_step_(ServoStep::TOP, t_open_v_ * i / (float)N, 100);
  append_step_(ServoStep::BOTTOM, b_home_v_, 200);

  // This is what the glide actually drives both servos to — keep the plan-time tracking
  // self-consistent with that rather than relying on every future caller to reset it
  // themselves before planning anything new (currently true of start_scan()/
  // execute_solution(), but not guaranteed for whatever's added next).
  plan_top_cover_ = TopCover::OPEN;
  plan_b_home_    = true;
  plan_b_cw_pos_  = false;
  plan_b_ccw_pos_ = false;

  step_idx_ = 0;
  state_    = SolverState::SERVO_TEST;
  enable_loop();
}

// ── Status publishing ──────────────────────────────────────────────────────────
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

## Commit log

2026-04-28 modified: README.md modified: custom_components/rubiks/__init__.py modified: custom_components/rubiks/button.py new file: custom_components/rubiks/cal_store.py deleted: custom_components/rubiks/camer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
2026-08-29 Add ESPHome robot component, HA↔ESP32 automations, and docs rebaseline
    Introduces the Phase 3 robot: a CUBOTino-derived ESP32-S3 arm (esphome/) that
    scans and physically solves the cube, bridged to the HA integration via typed
    actions/events (ha_automations/). Includes the TM1638 display/buzzer/LED
    status feedback, physical button actions, and a live moves-remaining
    countdown, all built and hardware-verified this round (including tracking
    down a wiring-harness short that briefly looked like a dead GPIO pin).
    Also: rewrites the architecture docs as current-state references (docs/),
    archiving prior versions; adds CLAUDE.md; polishes HA entity icons across
    button/sensor/number/text platforms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
    [rubiks_robot.yaml]
2026-08-30 Add TM1638 boot/connectivity feedback, fix first-press bug, HA icon polish
    ESPHome: RUBEE boot splash, READY/LOST API display states, and dedicated
    LED 7/8 status dots (believed-home, API connectivity) all driven by a
    connection-state watchdog. Adds on_error/on_success feedback (distinct
    error beep + logged reason) to the three homeassistant.action calls.
    Fixes a real bug where every TM1638 button's first press after boot did
    nothing — trigger_on_initial_state defaults false in ESPHome, so on_press
    never fired on a button's first-ever state publish.
    HA integration: icon pass across button/sensor/number/text entities
    (validated against real usage in a local HA core checkout); fixes two
    lat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
    [rubiks-solver.yaml]
2026-08-31 modified: README.md modified: custom_components/rubiks/rubiks_dashboard.yaml new file: docs/Images/Esp_cam/Gui1.png new file: docs/Images/Esp_cam/Rubee.jpeg new file: docs/Images/Esp_cam/esp32s3-cam.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
2026-09-05 modified: README.md deleted: docs/Images/Esp_cam/esp32s3-cam.jpg deleted: docs/archive/2026-08-15/collision-prevention.md deleted: docs/archive/2026-08-15/features.md deleted: docs/archive/2026-08-15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
    [rubiks-solver.yaml, rubiks_solver.cpp]
2026-09-05 new file: 3d_prints/Camera Holder.stl new file: 3d_prints/Camera Hood.stl new file: 3d_prints/TM1638 Cover.stl
    [Camera Holder.stl, Camera Hood.stl, TM1638 Cover.stl]
2026-09-06 modified: .gitignore modified: CLAUDE.md modified: README.md modified: custom_components/rubiks/manifest.json modified: docs/features.md modified: docs/servo-tuning.md modified: docs/spec.md modified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
2026-09-06 modified: .gitignore modified: CLAUDE.md modified: README.md new file: custom_components/rubiks/brand/icon.png modified: custom_components/rubiks/manifest.json modified: docs/features.md modified: do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
    [rubiks_robot.yaml]
2026-09-06 modified: README.md modified: docs/servo-tuning.md
2026-09-06 modified: docs/servo-tuning.md modified: esphome/rubiks-solver.yaml
2026-09-06 modified: .gitignore modified: LICENSE modified: README.md new file: custom_components/rubiks/LICENSE modified: custom_components/rubiks/manifest.json modified: custom_components/rubiks/sensor.py mod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
2026-09-07 deleted: ha_automations/rubiks_robot.yaml modified: CLAUDE.md modified: custom_components/rubiks/__init__.py modified: custom_components/rubiks/button.py modified: custom_components/rubiks/config_flo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
    [rubiks_robot.yaml]
2026-09-07 modified: CLAUDE.md modified: custom_components/rubiks/__init__.py modified: custom_components/rubiks/button.py modified: custom_components/rubiks/config_flow.py modified: custom_components/rubiks/co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
2026-09-07 modified: docs/collision-prevention.md modified: docs/orientation.md modified: docs/robot.md modified: docs/servo-tuning.md modified: esphome/rubiks-solver.yaml
    [rubiks-solver.yaml]
2026-09-09 Replace random-move scrambler with a robot-efficient generator
    Plain random scrambles waste most of their cost on faces that need
    reorienting before the robot can turn them. The new generator biases
    move selection toward whichever face is currently cheap to reach,
    while verifying every candidate against the real solver so efficiency
    never comes at the cost of an under-scrambled cube. Cuts the average
    robot-action count by roughly a third at the same scramble length.
